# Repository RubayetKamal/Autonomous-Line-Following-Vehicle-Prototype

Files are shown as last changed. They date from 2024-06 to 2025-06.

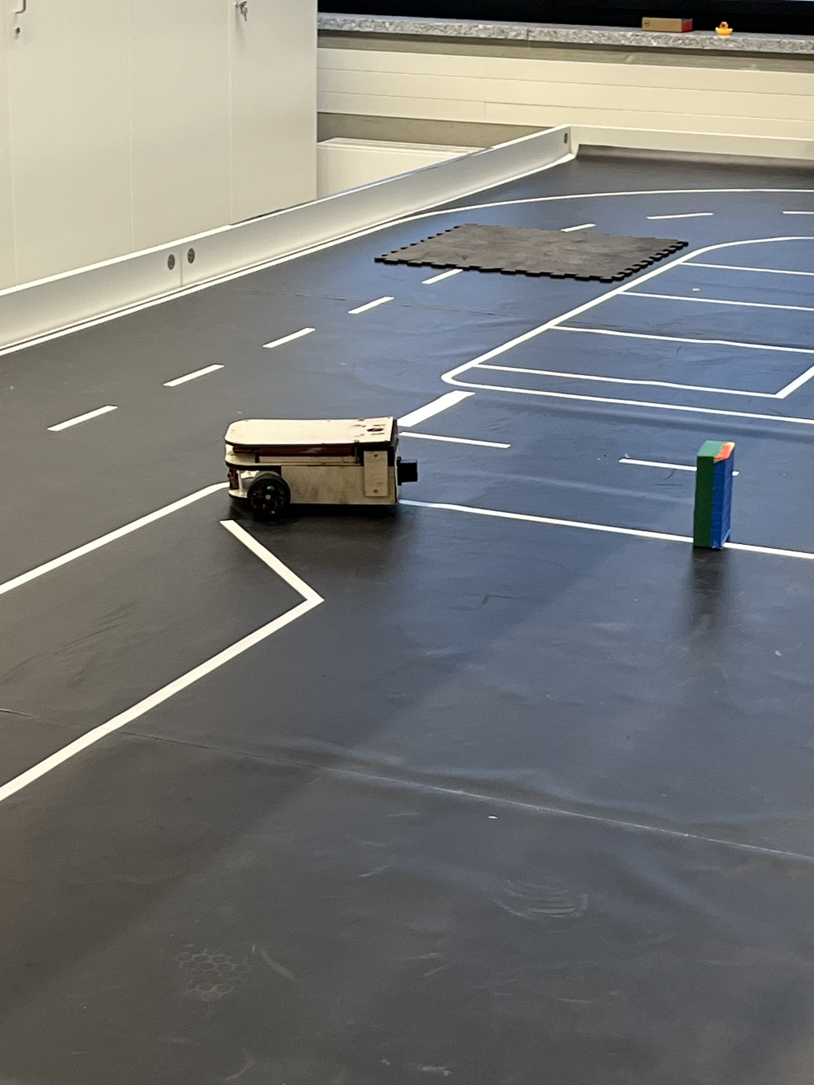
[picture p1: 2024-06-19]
Pictures/IMG_2329.jpg

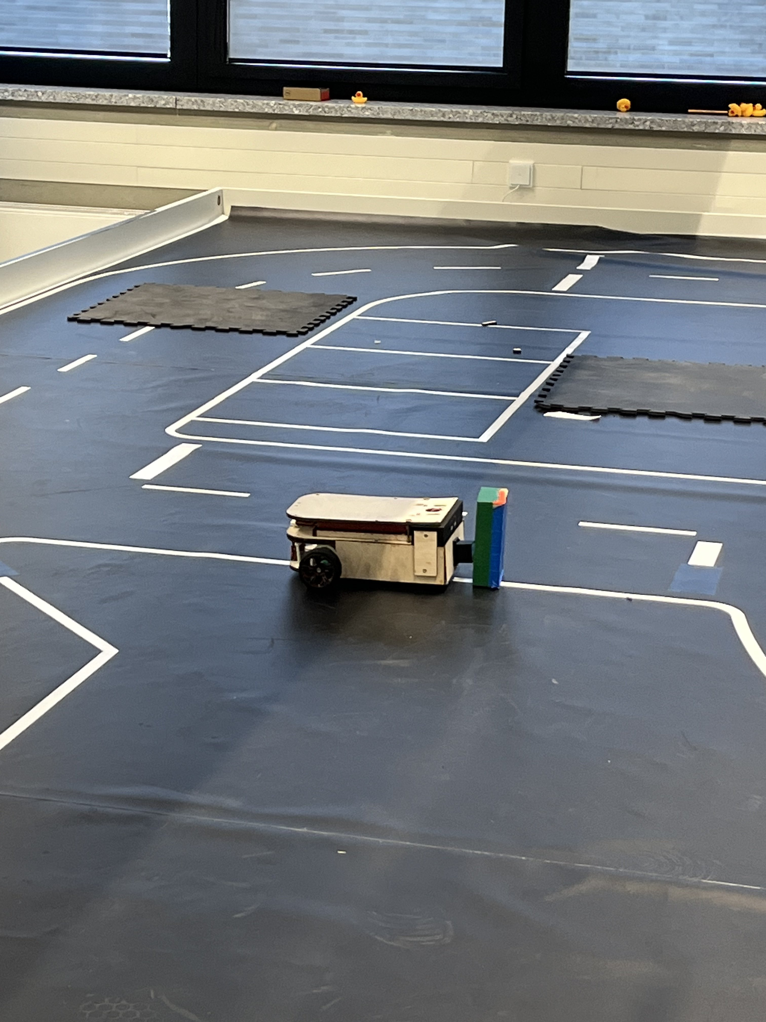
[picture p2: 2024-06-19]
Pictures/IMG_2333.jpg

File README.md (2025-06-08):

# Autonomous Line-Following Vehicle (AVR328P Project)

**Grade: 1,3**

This project involved developing a fully autonomous vehicle prototype using an AVR328P (Arduino Uno), capable of navigating a track independently while responding to environmental cues such as lines, colors, and obstacles.

## Highlights

- 🤝 Collaborated on system design and implementation as part of a team project.
- 🔄 Developed a finite state machine in C using the Arduino library to control vehicle behavior.
- 📍 Integrated a line sensor with an L298N motor driver to enable movement based on line detection.
- 🏎️ Optimized vehicle speed and control to handle a variety of track layouts, including 90° turns, ovals, and figure-eight shapes.
- 📡 Integrated the HC-SR04 ultrasonic sensor for real-time obstacle detection and evaluation.
- 🛠️ Designed and fabricated 2D/3D parts using SolidWorks/Fusion 360, with materials such as PLA and wood, based on collaborative planning.
- 🎨 Calibrated the TCS3200 color sensor to detect specific surroundings and trigger actions like parking or route changes based on detected color.
- 🧩 Modeled the system using SysML after thoroughly analyzing project goals and requirements.

🏆 **Awarded for implementing the most features involving color detection.**

More detailed documentation and attachments are available in this repository.

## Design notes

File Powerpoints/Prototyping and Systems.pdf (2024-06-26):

# PROTOTYPING & SYSTEMS ENGINEERING

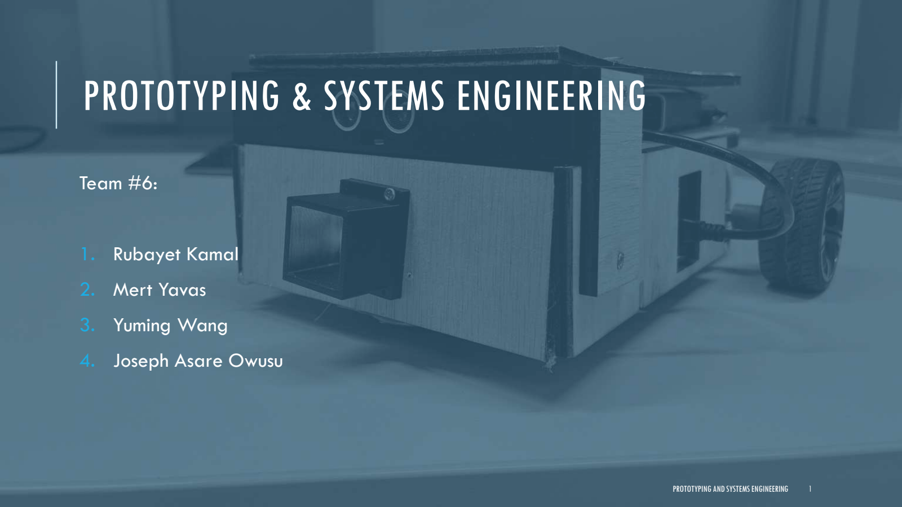
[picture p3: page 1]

# Team #6:

# 1. Rubayet Kamal

# 2. Mert Yavas

# 3. Yuming Wang

# 4. Joseph Asare Owusu

PROTOTYPING AND SYSTEMS ENGINEERING

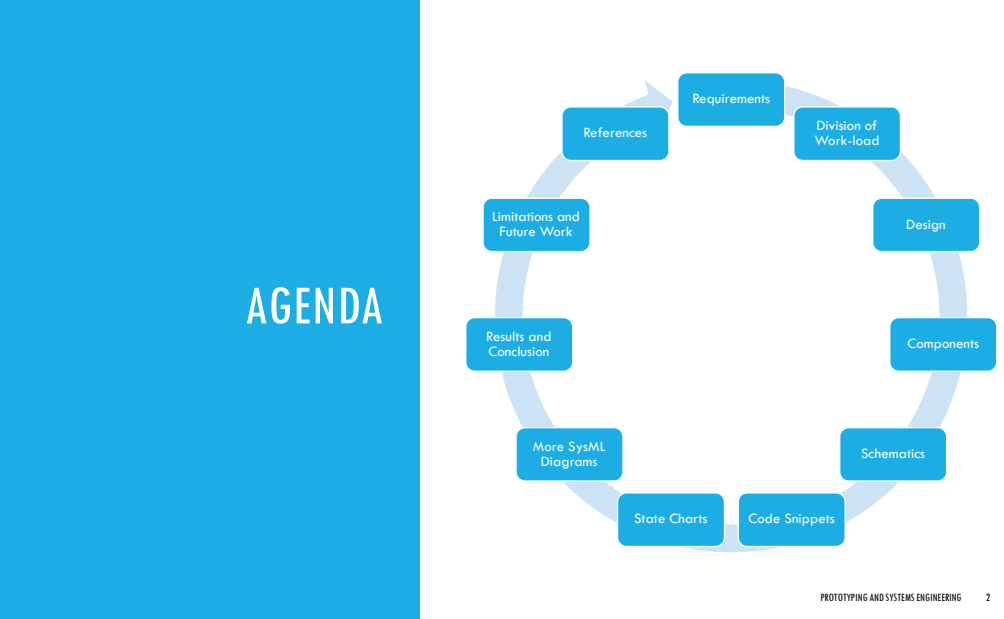
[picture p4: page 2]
AGENDA; PROTOTYPING AND SYSTEMS ENGINEERING; Requirements; Division of Work-load; Design; Components; Schematics; State Charts; Code Snippets; More SysML Diagrams; Results and Conclusion; Limitations and Future Work; References

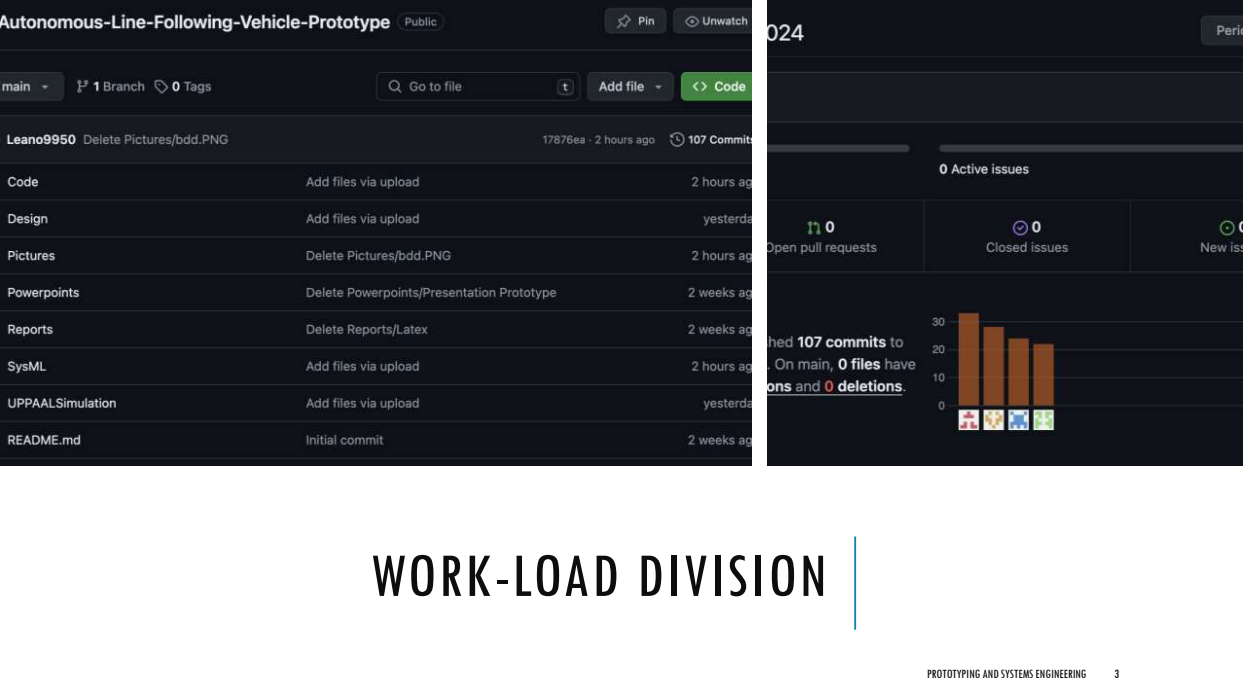
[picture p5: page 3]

WORK-LOAD DIVISION

# Requirements

# Can Follow a Line?

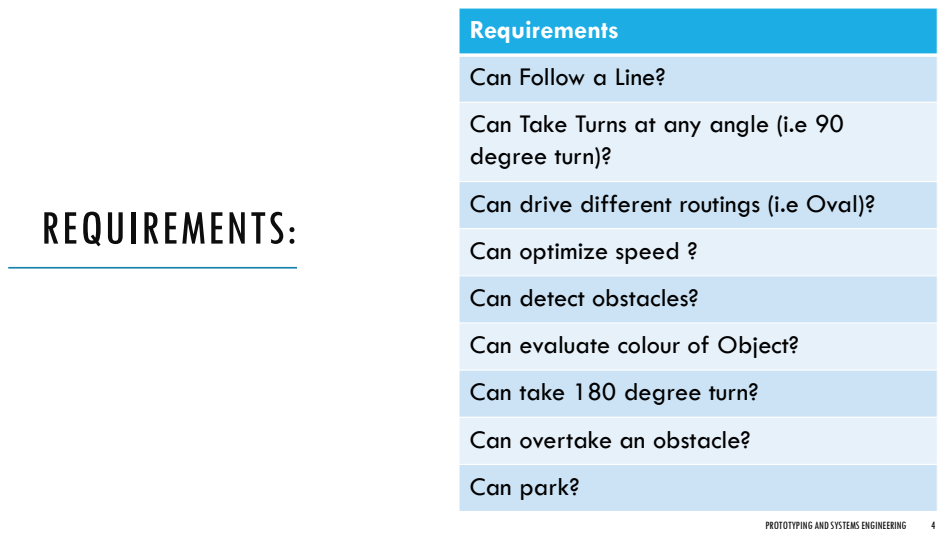
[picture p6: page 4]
REQUIREMENTS:; Can park?

Can Take Turns at any angle (i.e 90
degree turn)?

Can drive different routings (i.e Oval)?

Can optimize speed ?

Can detect obstacles?

Can evaluate colour of Object?

Can take 180 degree turn?

Can overtake an obstacle?

[1]

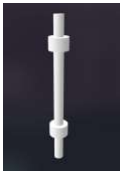
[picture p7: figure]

# PARTS DESIGNED

# VIA SOLIDWORKS AND FUSION 360

## ☐Designed in Solidworks and

Fusion 360.

## ☐.dxf files to laser cut with

wood.

☐.stl to 3D print via PLA.

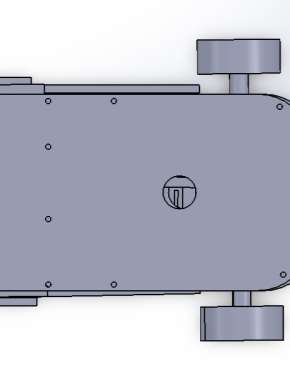
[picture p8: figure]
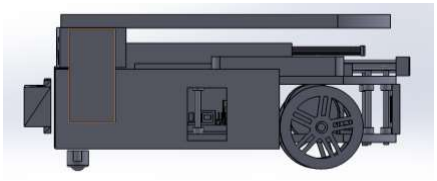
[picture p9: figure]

# FINAL DESIGN

•No components are glued.

•All components are screwed in.

•100 percent modifiable.

[2]

[2]

# SENSORS:

## To Detect Obstacles

## To Detect Change in Line

To Detect Obstacle Color | HC SR-04 Ultrasonic Sensor (Maximum range: 14 cm)
ST 1140 Line Sensor | TCS3200 Color Sensor

[3]

[5]

[4]

# ACTUATORS:

To move the car in any direction.

## - DC Motors (2x)

## - L298N Motor Driver

- Input of 12V from Battery.

## - Output of 5V to Arduino - Used to control speed and

direction of DC Motors.

[6]

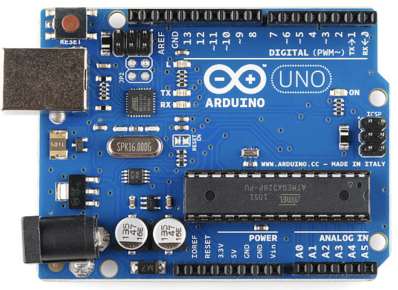
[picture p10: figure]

# MICROCONTROLLER AND POWER SOURCE:

## - 5V Input - 14 Digital Pins - 6 Analog Pins - Used with Arduino IDE

## - Technology LiPo - Cell number 2 - Tension 7.4V - Capacity 3000mAh - Resilience 20C - Weight 210g

- Brain and Energy source of the car.

[8]

[9]

# SCHEMATICAL VIEW FOR HCSR04

Pin Configuration on Ultrasonic Sensor | Pin Configuration on Arduino
Vcc | 5V
TRIG | 4
ECHO | 5
GND | GND

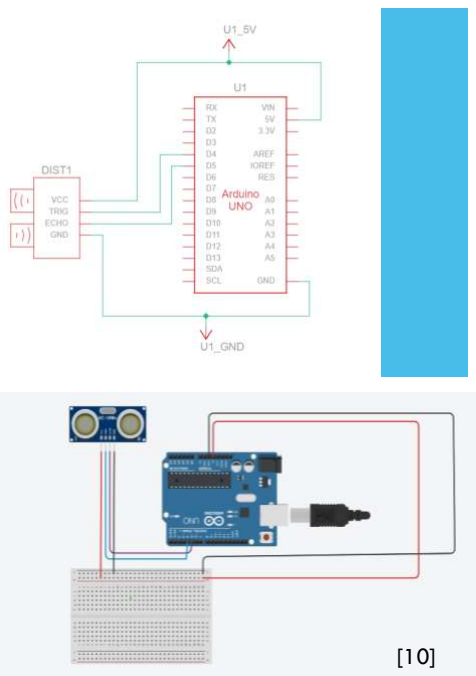
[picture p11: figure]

PROTOTYPING AND SYSTEMS ENGINEERING | 12 [10]

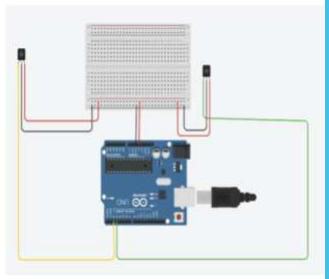
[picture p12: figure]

# SCHEMATICAL VIEW FOR LINE DETECTOR:

Pin on Sensor | Pin Configuration on Arduino
Vcc | 5V
GND | GND
OUTPUT 1 | 2
OUTPUT 2 | 3

[10]

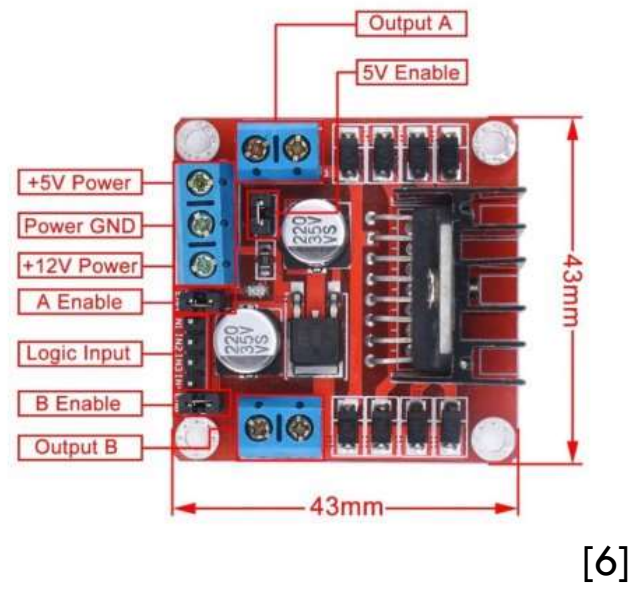
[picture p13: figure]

# SCHEMATICAL VIEW OF

L298N

Pin on Sensor | Pin on Configuration | on Arduino
and | components
IN1 | 10
IN2 | 9
IN3 | 8
IN4 | 7
ENABLE A | 11
ENABLE B | 6
OUTPUT A | MOTOR
OUTPUT B | MOTOR
5V POWER | Vcc
POWER GND | GND
12V POWER | BATTERY

[10]

# SCHEMATICAL VIEW OF TCS3200

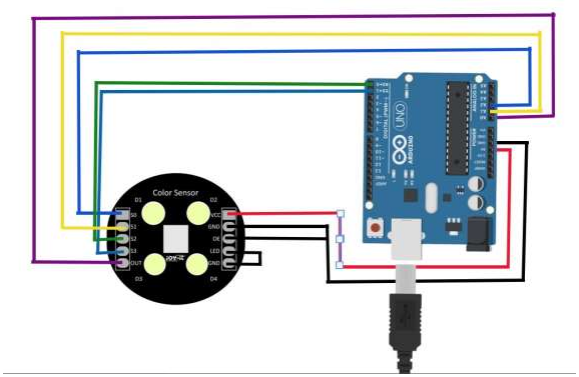
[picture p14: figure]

Pin | on | Sensor | Pin | Configuration on | Arduino
S0 | | | A2
S1 | | | A1
S2 | | | 0
S3 | | | 1
OUT | A0
Vcc | | | 5V
GND | GND
OE | GND
LED | GND
GND | LED

[10]

# COMPLETE SCHEMATIC

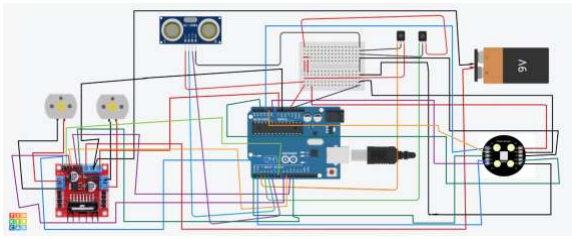
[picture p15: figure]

[10]

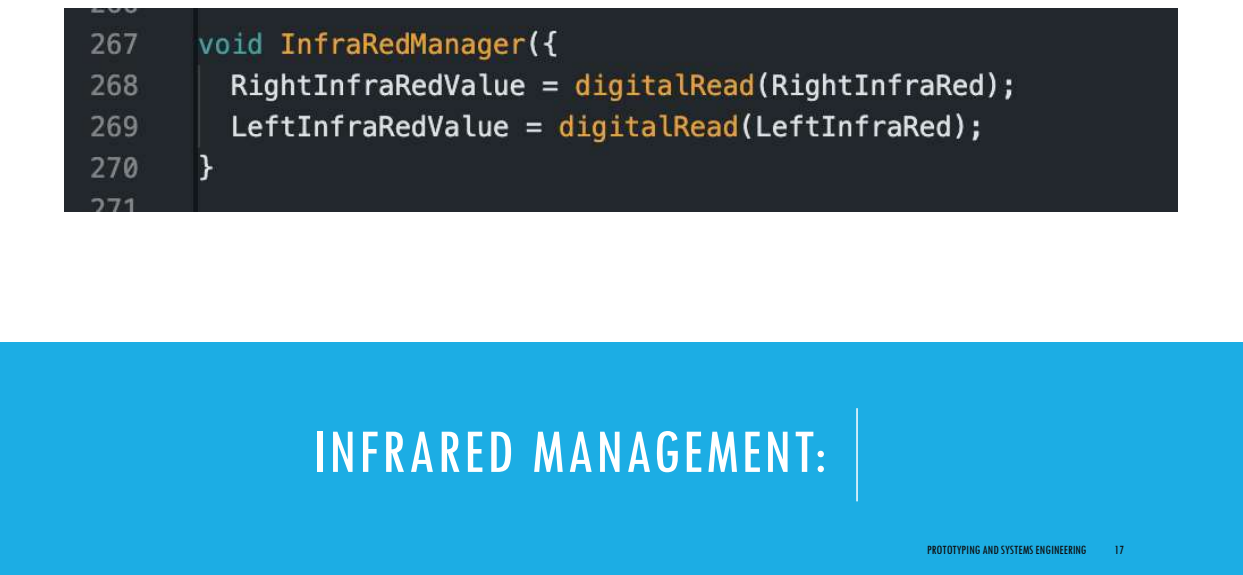
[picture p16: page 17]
INFRARED MANAGEMENT:

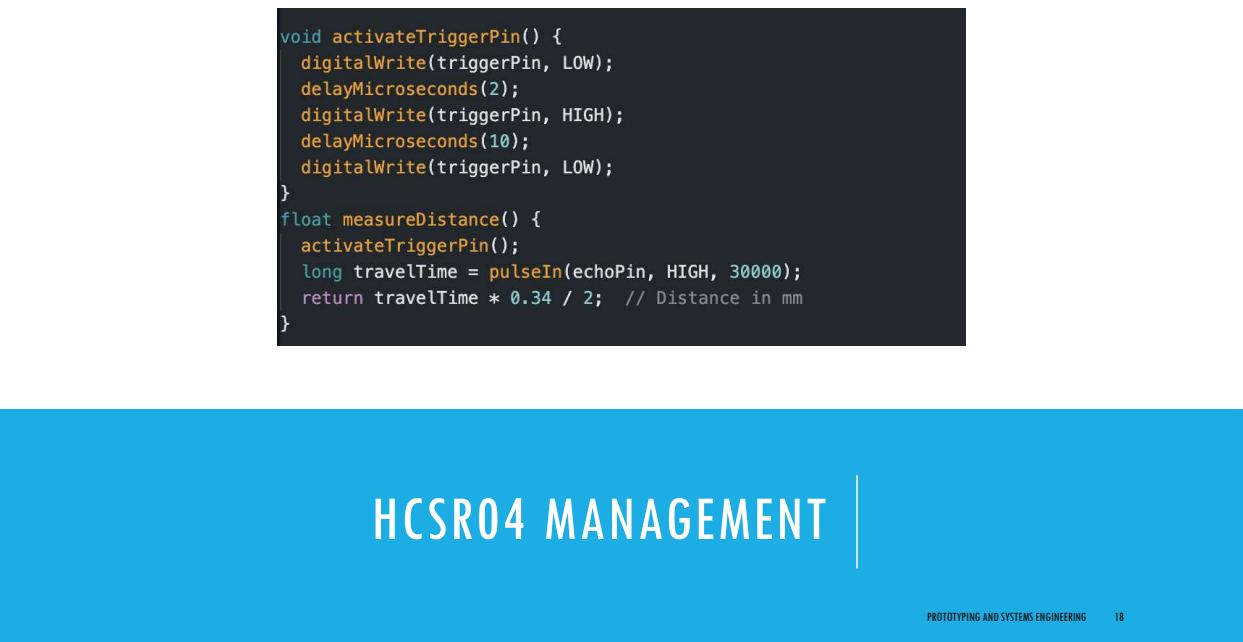
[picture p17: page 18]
HCSR04 MANAGEMENT

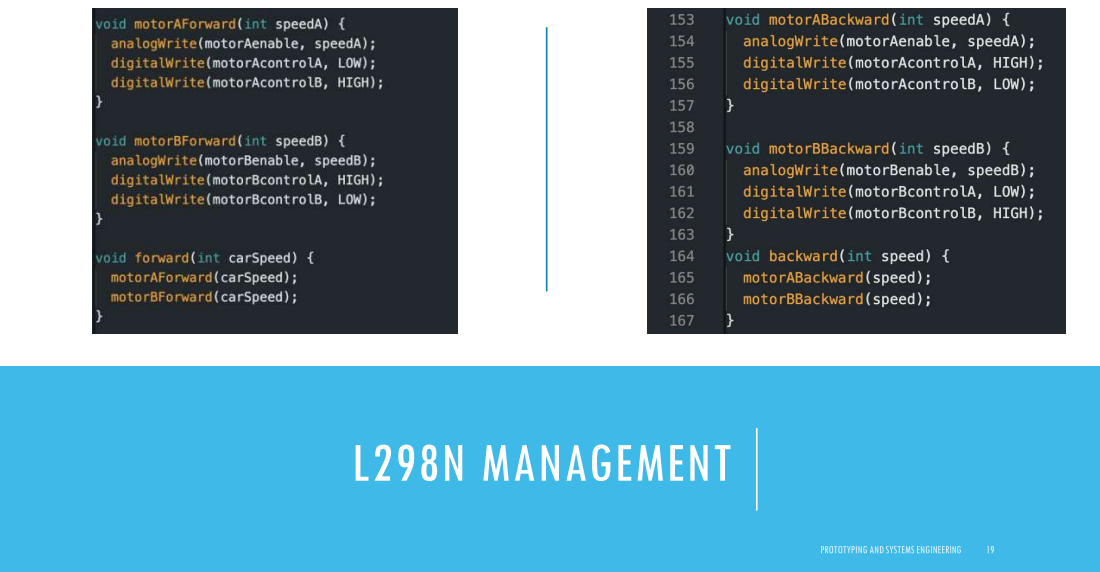
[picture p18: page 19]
L298N MANAGEMENT

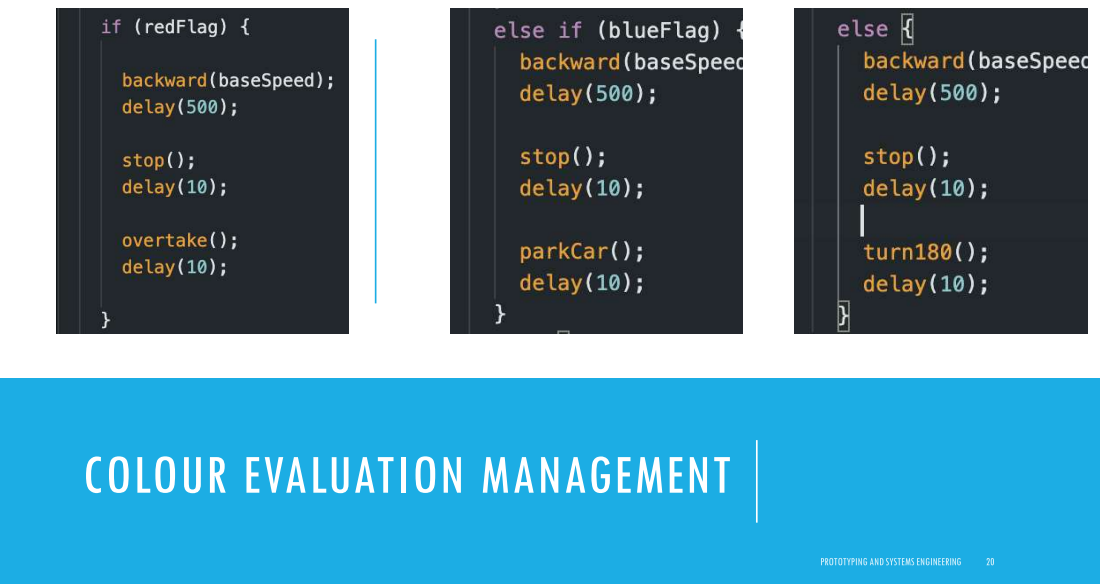
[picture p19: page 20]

COLOUR EVALUATION MANAGEMENT

## State Machine Diagram

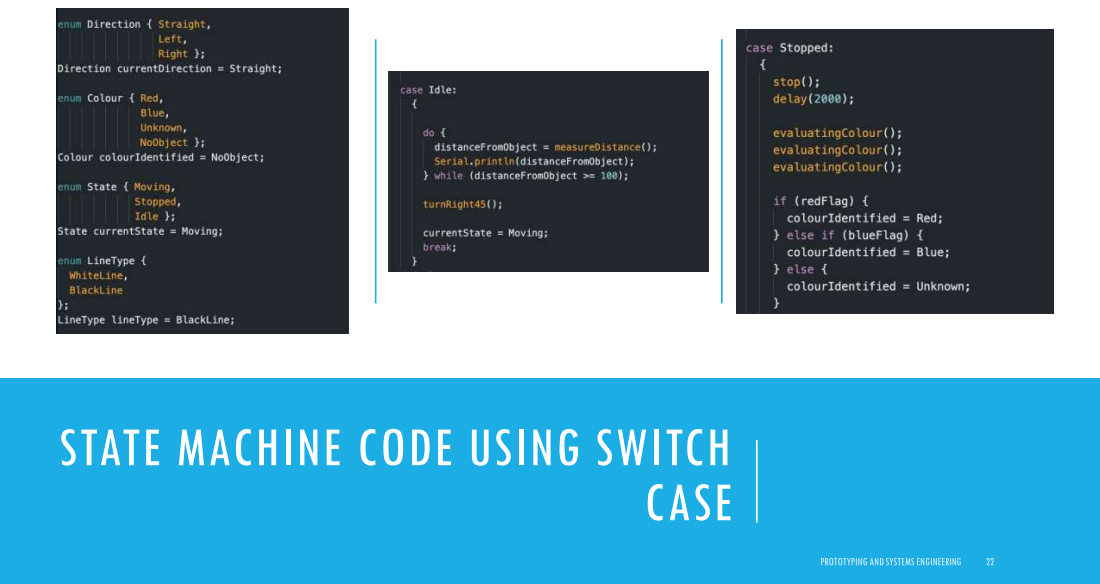
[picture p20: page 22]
CASE

STATE MACHINE CODE USING SWITCH

## Activity Diagram

## Operate Vehicle

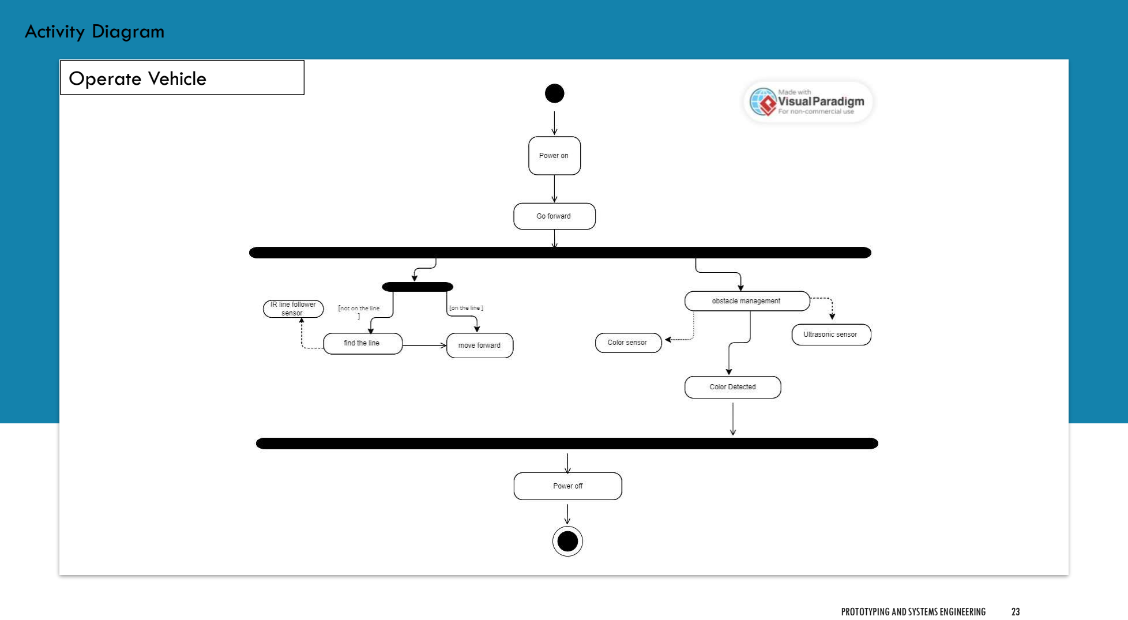
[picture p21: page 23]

## bdd[package][autonomous vehicle prototype]

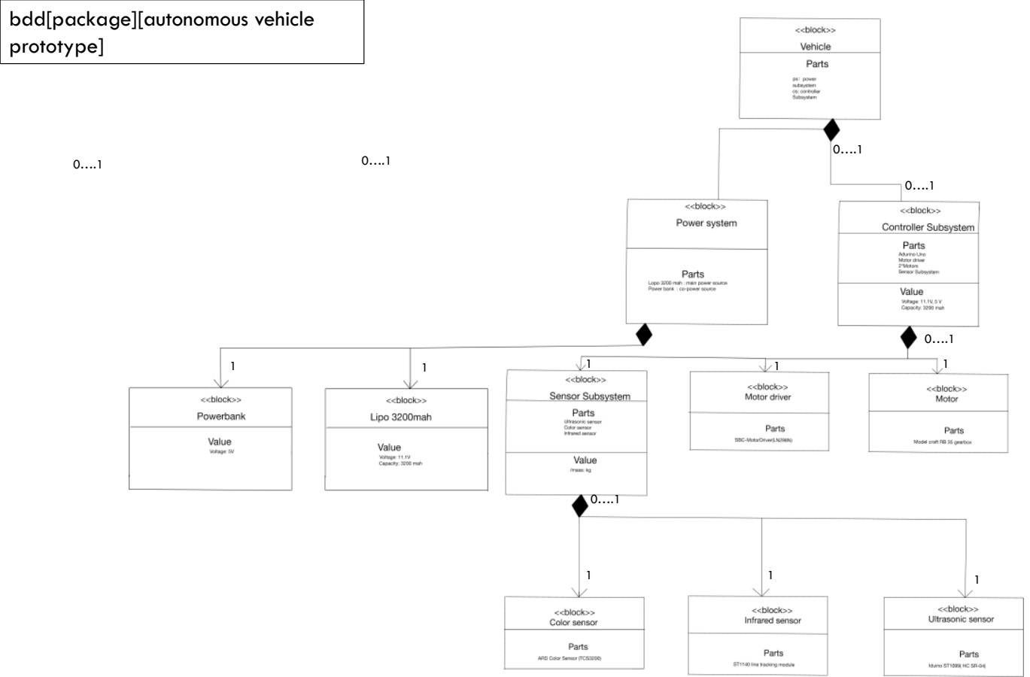
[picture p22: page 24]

1

0….1

0….1

0….1

0….1

1 | 1

0….1 0….1

1 | 1

1

1 | 1

# INTERACTION STRUCTURE

# FOR COLOUR EVALUATION

# INTERACTION STRUCTURE

# FOR FOLLOWING LINE

# INTERACTION STRUCTURE FOR OBSTACLE MANAGEMENT

# RESULTS AND ACCOMPLISHMENT

Requirements | Result
Can Follow a Line? | ✓
Can Take Turns at any angle (i.e 90 degree turn)? | ✓
Can drive different routings (i.e Oval)? | ✓
Can optimize speed ? | ✓
Can detect obstacles? | ✓
Can evaluate colour of Object? | ✓
Can take 180 degree turn? | ✓
Can overtake an obstacle? | ✓
Can park? | ✓

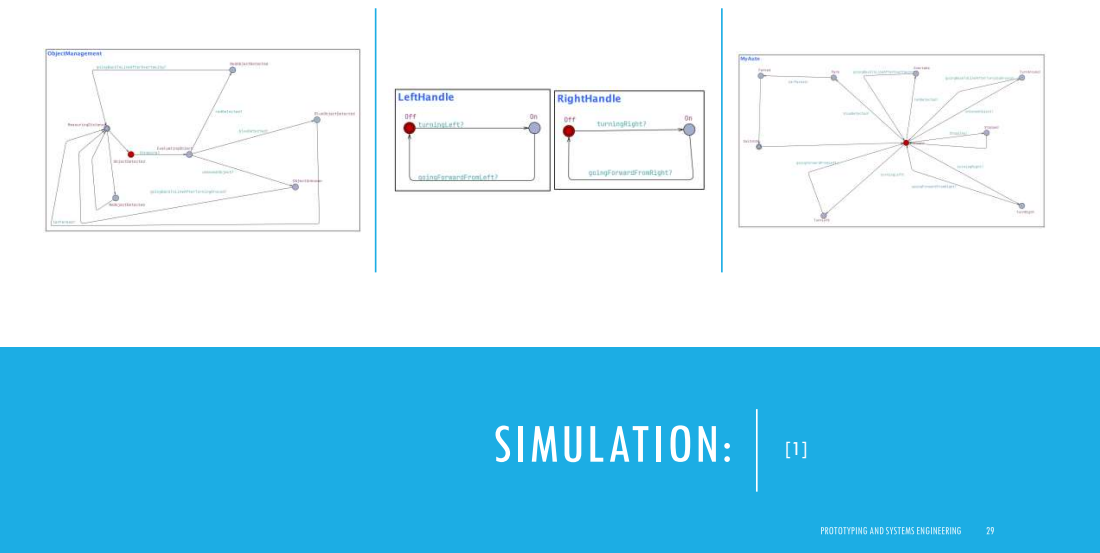
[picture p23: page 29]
SIMULATION:

# CAR FOLLOWING LINE:

# CAR TAKING TURN AT 90 DEGREES:

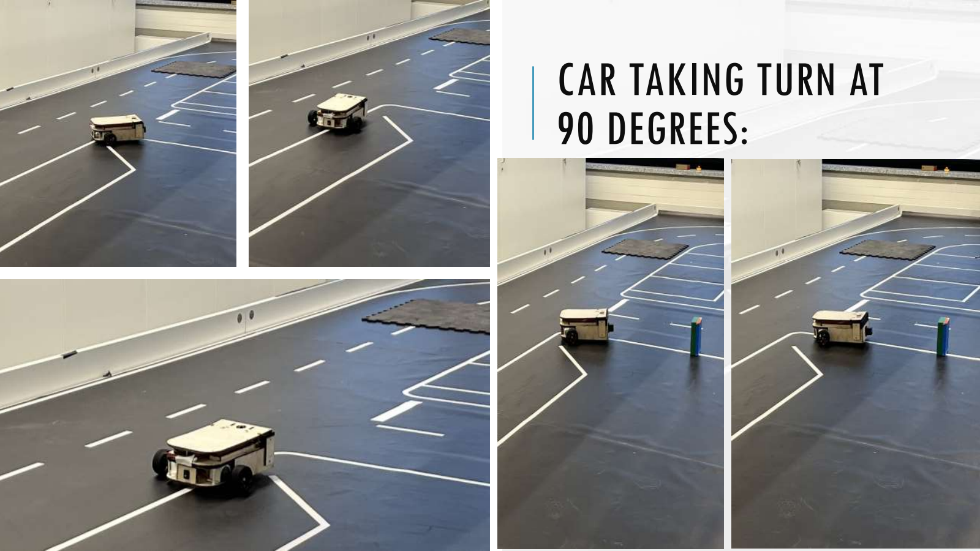
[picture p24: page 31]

# CAR DETECTING OBSTACLE:

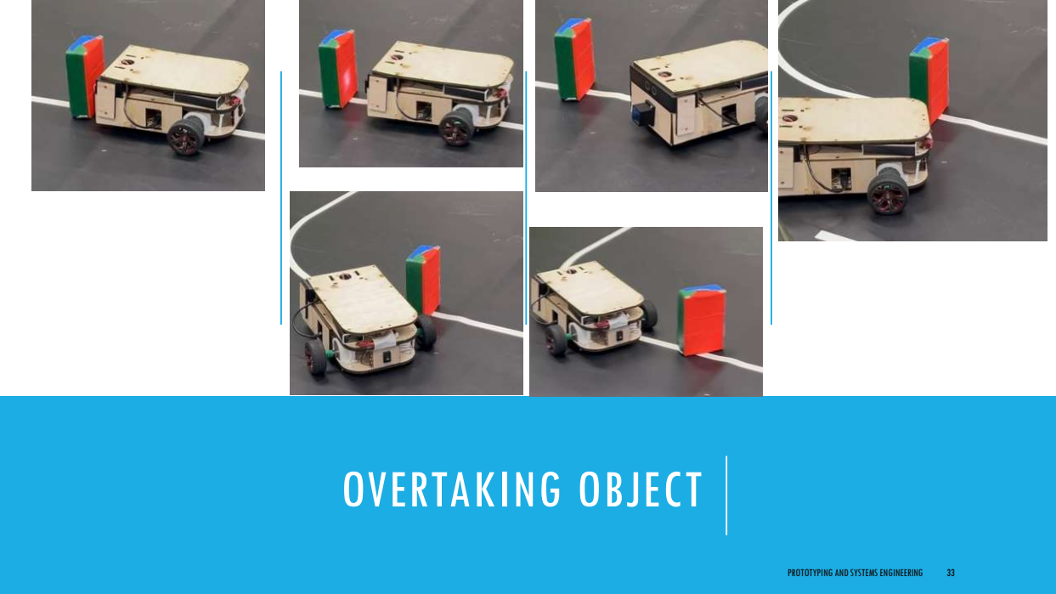
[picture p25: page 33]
OVERTAKING OBJECT

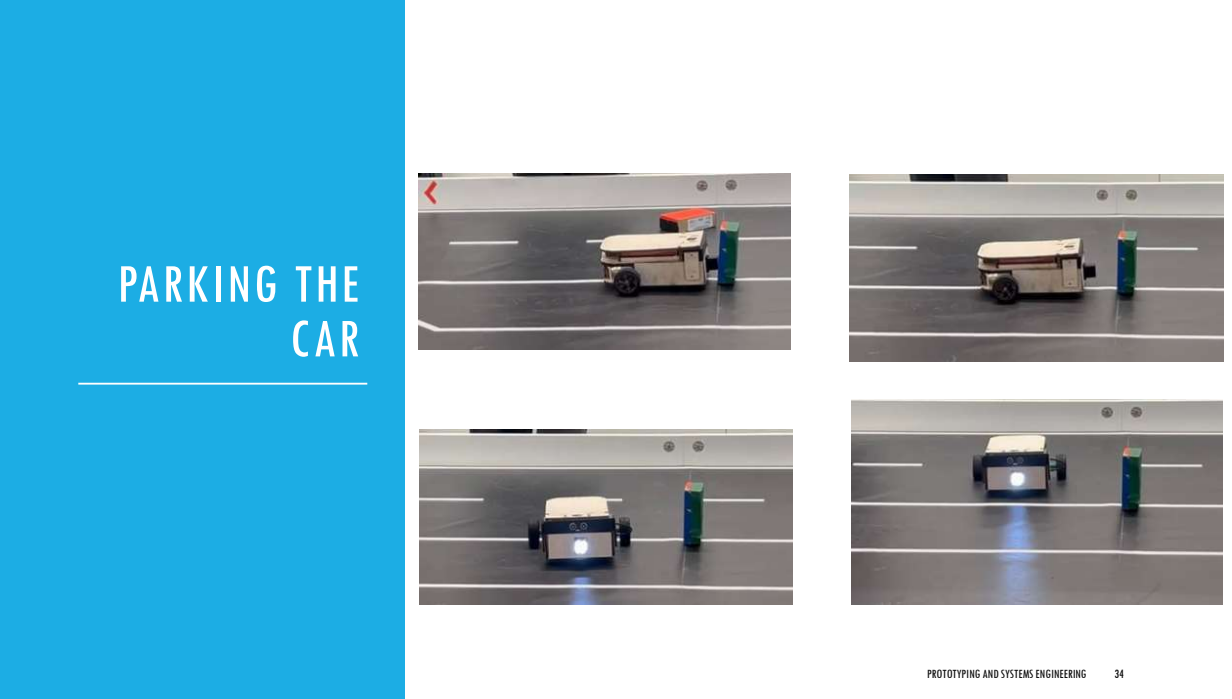
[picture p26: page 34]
PARKING THE CAR

# TURNING 180

# FUTURE WORK:

# 4 wheeled autonomous vehicle

prototype.

# Using Servo front and back to move the ultrasonic so that it can scan

surroundings.

# Will probably need to switch to a different microcontroller as digital

pins in Arduino are limited.

# Maybe use with a Real-Time Operating System for better

response.

[12]

# REFERENCES:

[1] “Uppaal,” UPPAAL, https://uppaal.org/ (accessed Jun. 20, 2024).
[2] “3D CAD Design Software,” SOLIDWORKS, https://www.solidworks.com/ (accessed Jun. 20, 2024).
[3] “Ultrasonic sensor,” Joy, https://joy-it.net/files/files/Produkte/SEN-US01/SEN-US01_Manual_2024-04-15.pdf (accessed Jun. 19, 2024).
[4] “Colorimeter,” https://joy-it.net, https://www.joy-it.net/files/files/Produkte/SEN-Color/SEN-Color_Manual_2021-08-18.pdf (accessed Jun. 19, 2024).
[5] “KY-033 linetracking sensor,” SensorKit, https://sensorkit.joy-it.net/en/sensors/ky-033 (accessed Jun. 20, 2024).
[6] “L298N motor driver module,” Components101, https://components101.com/modules/l293n-motor-driver-module (accessed Jun. 20, 2024).
[7] DC Motor, https://www.handsontec.com/dataspecs/775-Motor.pdf (accessed Jun. 21, 2024).
[8] T. A. Team, “Arduino hardware,” Arduino, https://www.arduino.cc/en/hardware (accessed Jun. 20, 2024).
[9] “Buy Conrad Energy Scale Model Battery Pack (LIPO) 14.8 V 5500 mah no. of cells: 4 20 C Softcase XT90,” Conrad Electronic, https://www.conrad.com/en/p/conrad-energy-scale-model-battery-pack-lipo-14-8-v-5500-mah-no-of-cells-4-20-c-softcase-xt90-1344151.html (accessed Jun. 20, 2024). (https://www.conrad.com/en/p/conrad-energy-scale-model-battery-pack-lipo-14-8-v-5500-mah-no-of-cells-4-20-c-softcase-xt90-1344151.html)
[10] Tinkercad, https://www.tinkercad.com/dashboard (accessed Jun. 20, 2024).
[11] “Online productivity suite,” Visual Paradigm - Online Productivity Suite, https://online.visual-paradigm.com/ (accessed Jun. 20, 2024).
[12] Explore 685+ free racing cars illustrations: Download now - pixabay, https://pixabay.com/illustrations/ai-generated-mouse-racing-car-car-8674235/ (accessed Jun. 20, 2024). (https://pixabay.com/illustrations/ai-generated-mouse-racing-car-car-8674235/)

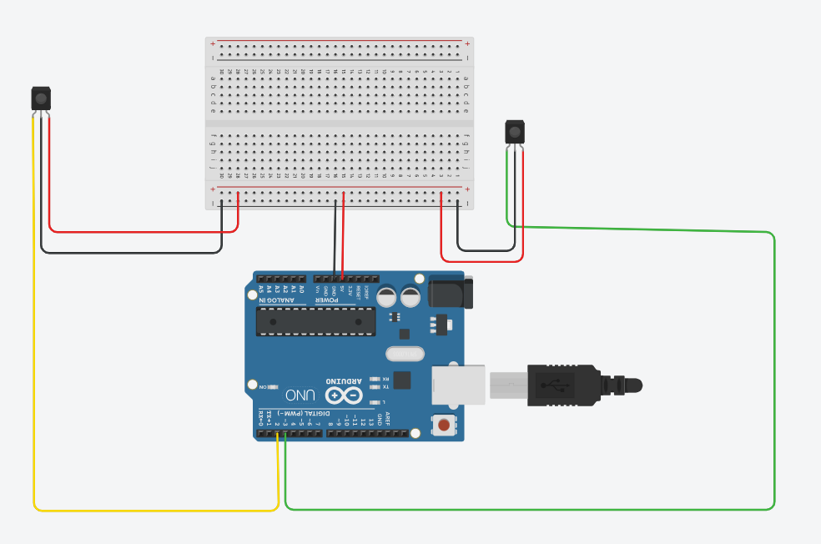
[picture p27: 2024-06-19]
Pictures/ir schematic .png

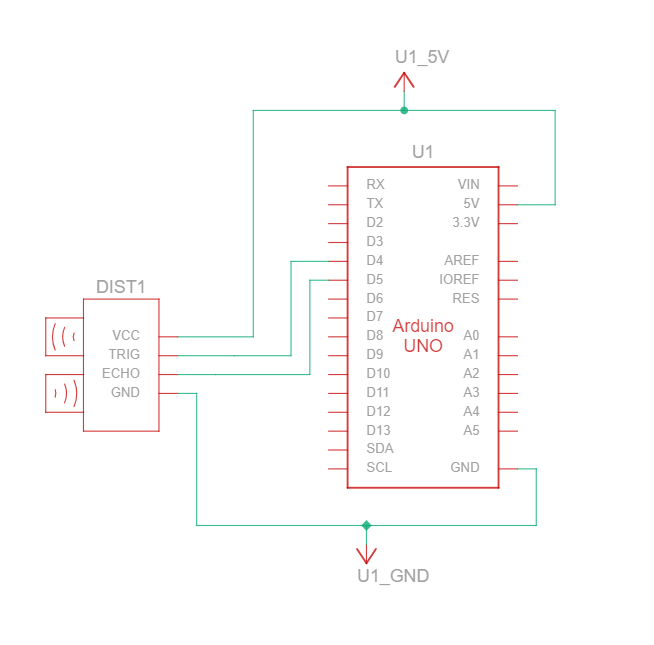
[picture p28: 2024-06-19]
Pictures/ultrasonic schematic.png

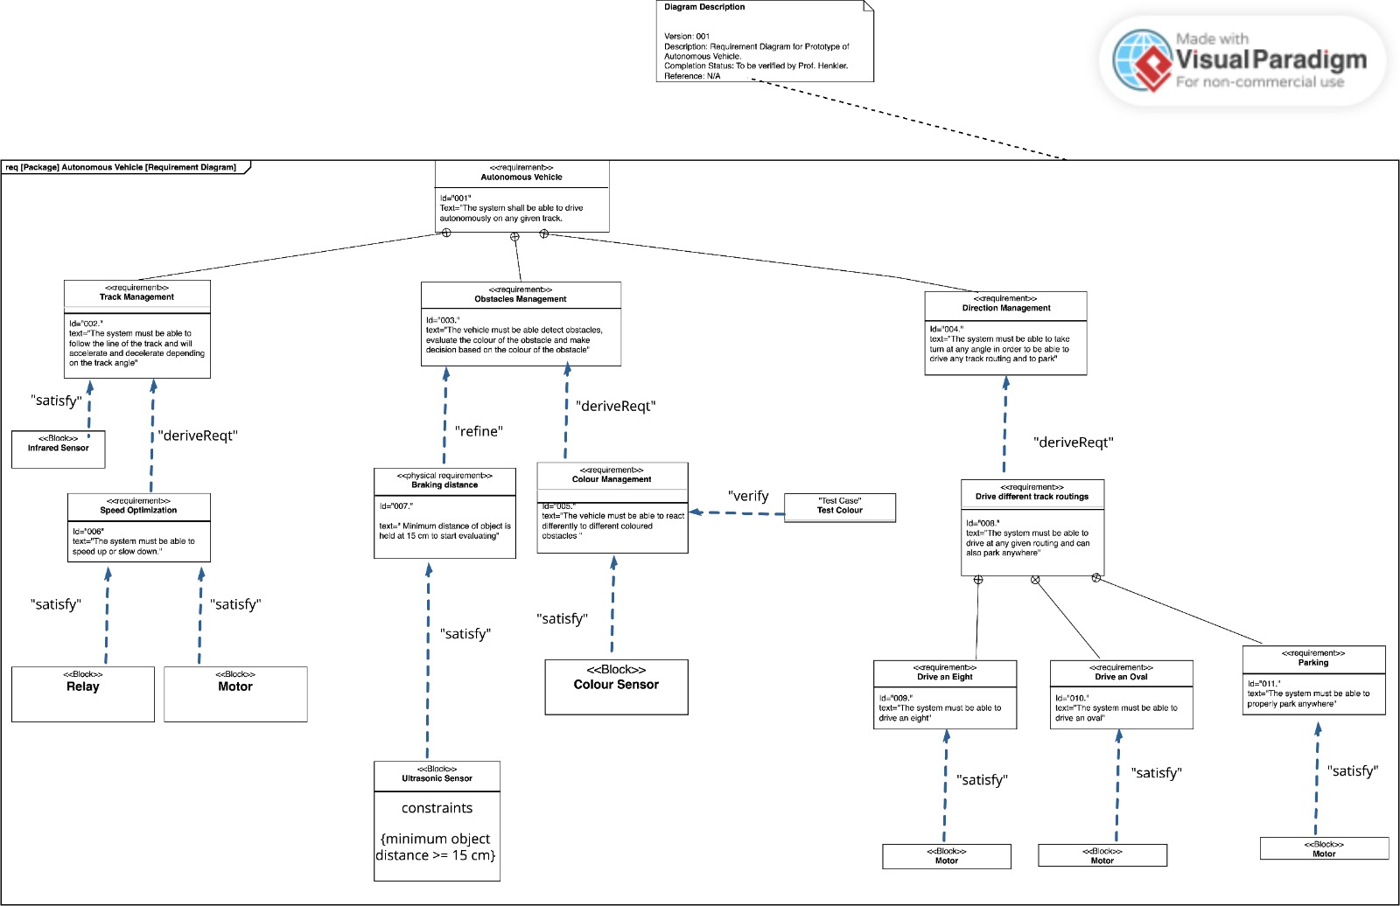
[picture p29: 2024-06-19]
SysML/requirement diagram.jpg

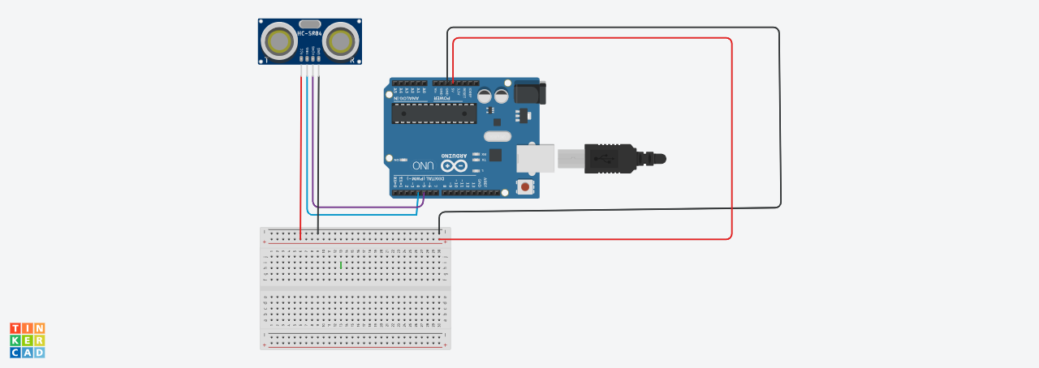
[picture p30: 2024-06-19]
Pictures/Glorious Elzing (1).png

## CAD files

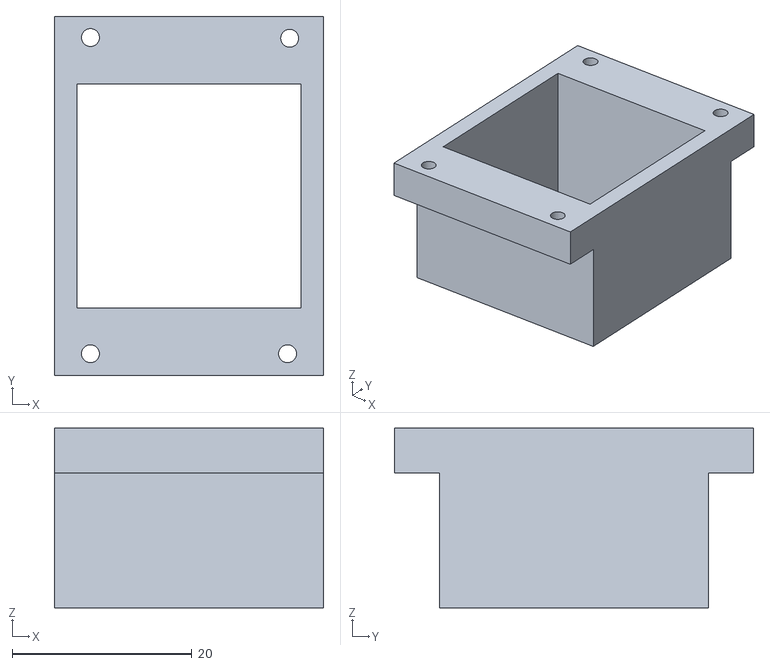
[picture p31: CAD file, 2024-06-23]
Design/ColourSensorCoverAGAIN.stl
30.0 x 40.0 x 20.0

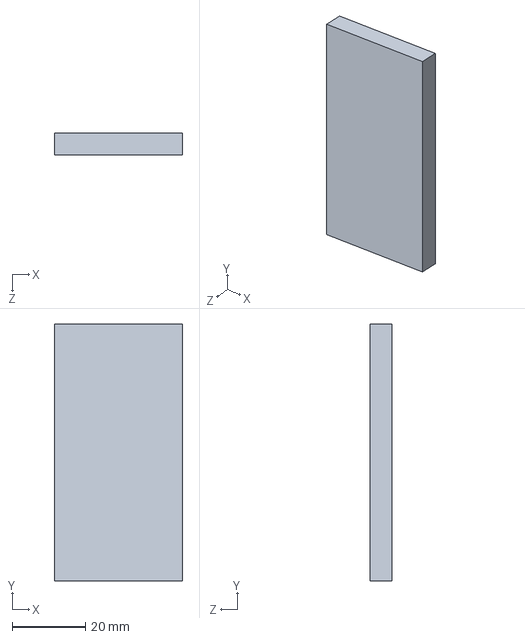
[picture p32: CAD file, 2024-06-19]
Design/ultrasonicSupportHolder.SLDPRT
35.0 x 70.0 x 6.00 mm

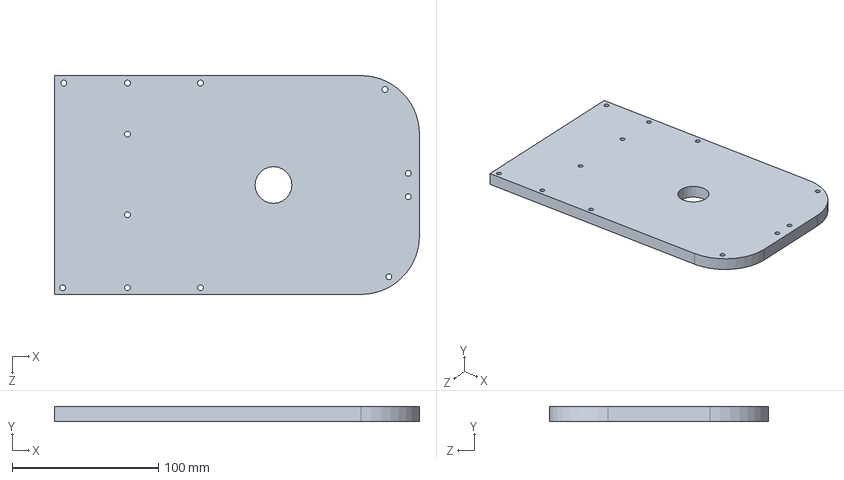
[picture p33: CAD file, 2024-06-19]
Design/Wood10mm.SLDPRT
250.0 x 10.0 x 150.0 mm

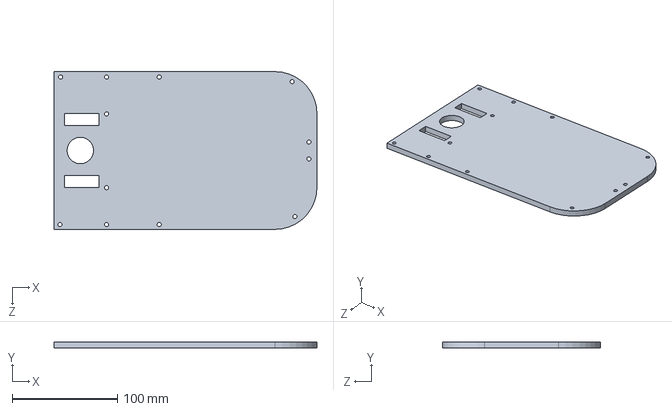
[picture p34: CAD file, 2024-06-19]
Design/Wood6mm.SLDPRT
250.0 x 6.00 x 150.0 mm

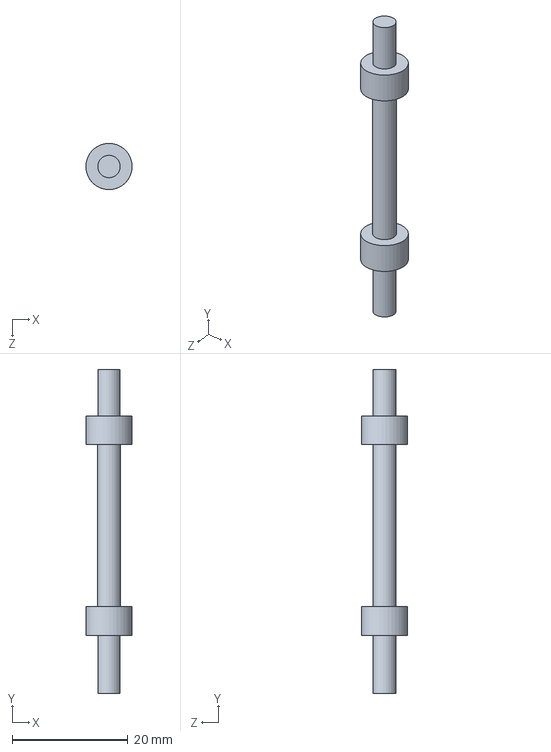
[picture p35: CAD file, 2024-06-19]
Design/supportStick.SLDPRT
7.99 x 56.0 x 8.00 mm

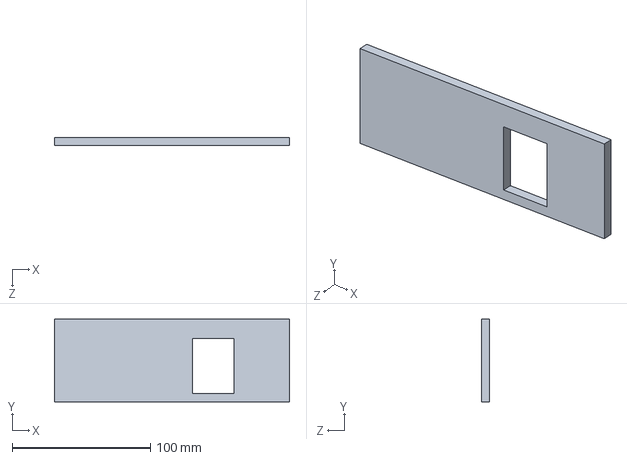
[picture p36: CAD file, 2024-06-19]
Design/sideCoverCable.SLDPRT
170.0 x 60.0 x 6.00 mm

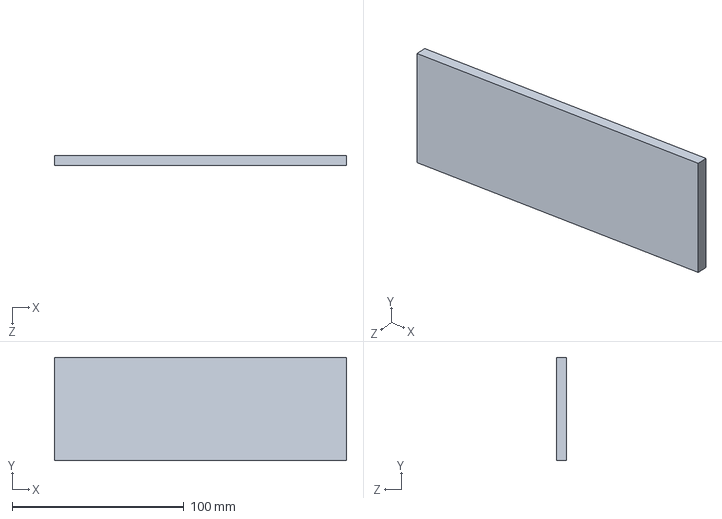
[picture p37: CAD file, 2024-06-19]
Design/sideCover.SLDPRT
170.0 x 60.0 x 6.00 mm

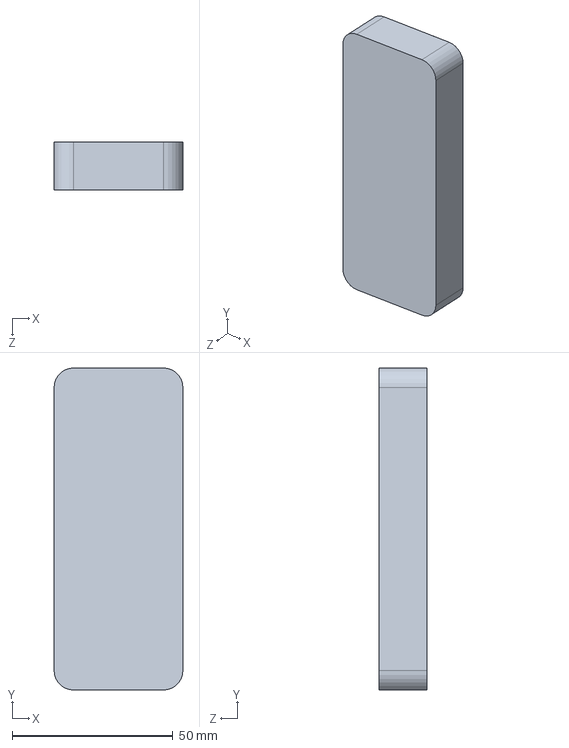
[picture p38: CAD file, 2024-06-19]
Design/powerbank.SLDPRT
40.0 x 100.0 x 15.0 mm

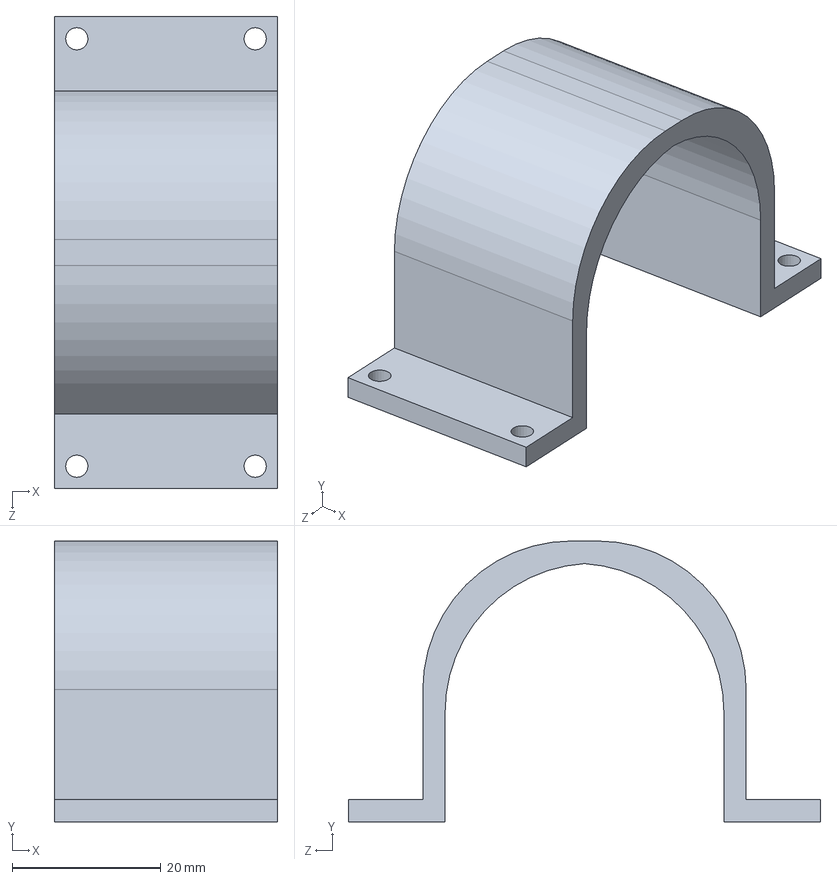
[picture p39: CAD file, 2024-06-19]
Design/motorholder5.SLDPRT
30.0 x 37.8 x 63.5 mm

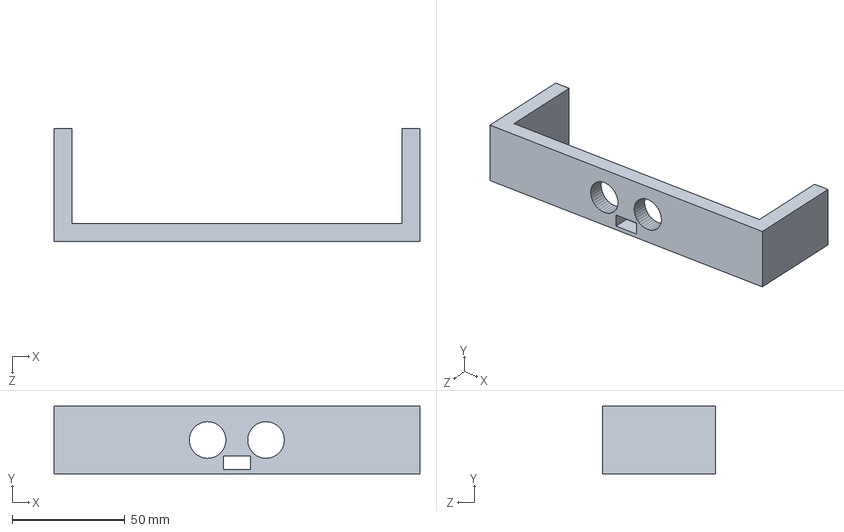
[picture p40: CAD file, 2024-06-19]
Design/Front.SLDPRT
162.0 x 30.0 x 50.0 mm

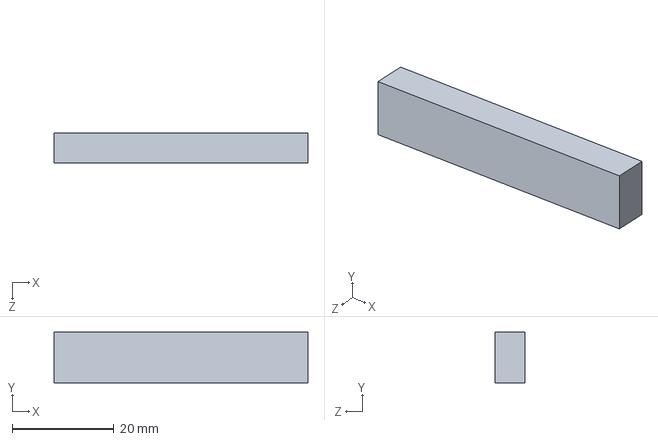
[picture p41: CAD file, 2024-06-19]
Design/batteryHolderShort.SLDPRT
50.0 x 10.0 x 6.00 mm

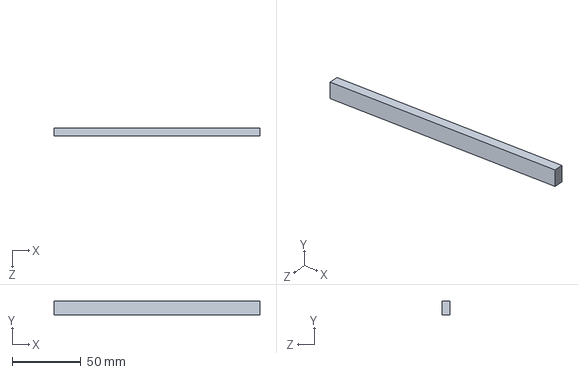
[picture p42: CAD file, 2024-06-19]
Design/batteryHolderLong.SLDPRT
150.0 x 10.0 x 6.00 mm

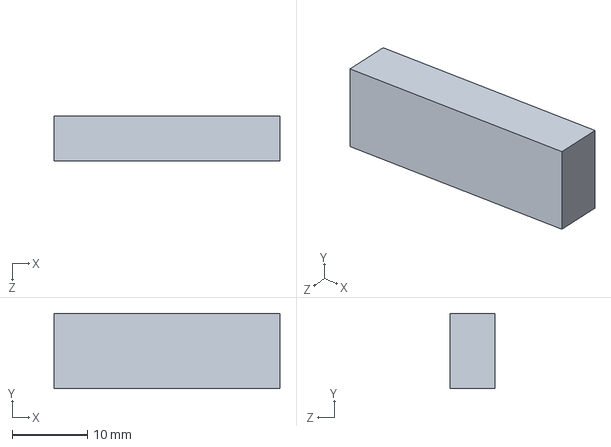
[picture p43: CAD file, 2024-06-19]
Design/batterHolderCable.SLDPRT
30.0 x 10.0 x 6.00 mm

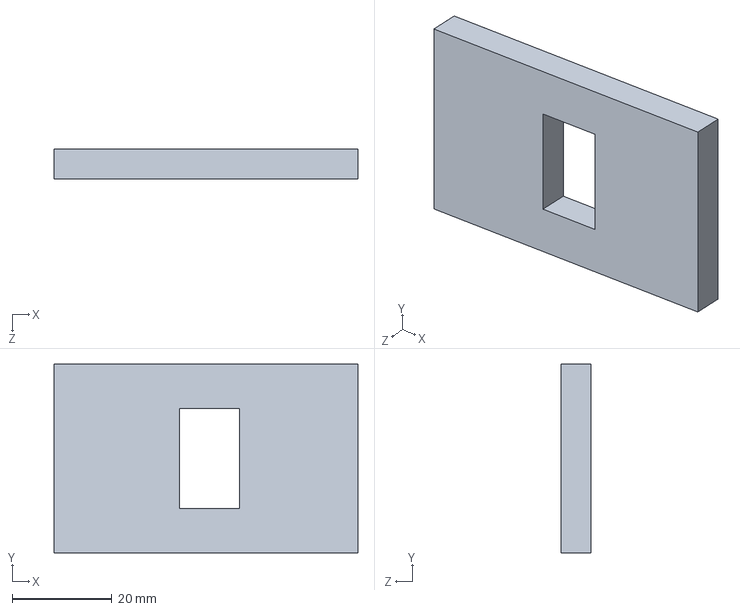
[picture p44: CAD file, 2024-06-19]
Design/backCover.SLDPRT
61.0 x 37.8 x 6.00 mm

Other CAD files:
Design/assembliedCar.SLDASM
Design/ColourSensorCover v2.stl
Design/Front.stl
Design/Wood10mm.DXF
Design/Wood6mm.DXF
Design/assembliedCarSheet.SLDDRW
Design/backCover.DXF
Design/batterHolderCable.DXF
Design/batteryHolderLong.DXF
Design/batteryHolderShort.DXF
Design/motorholder5.STL
Design/sideCover.DXF
Design/sideCoverCable.DXF

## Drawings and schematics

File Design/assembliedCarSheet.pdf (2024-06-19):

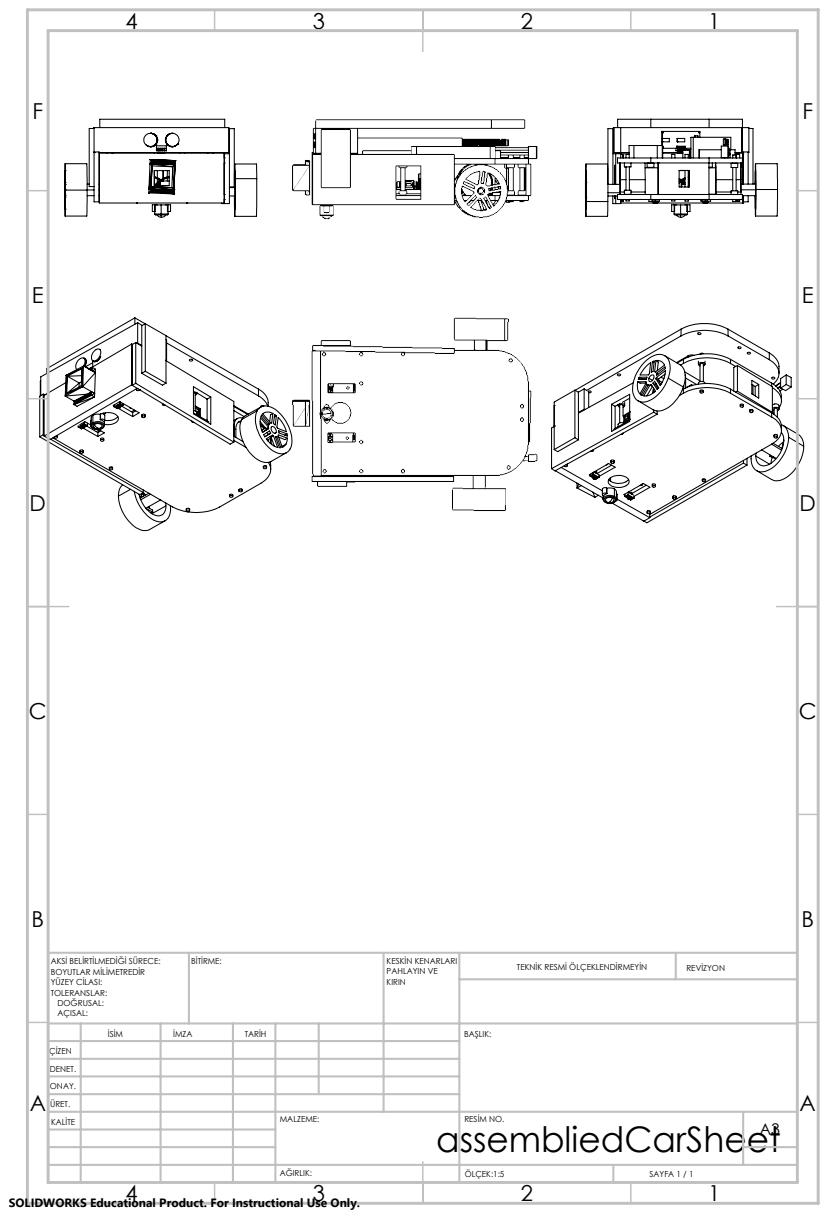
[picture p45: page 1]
BİTİRME:; KESKİN KENARLARI; PAHLAYIN VE; TEKNİK RESMİ ÖLÇEKLENDİRMEYİN; REVİZYON; ÖLÇEK:1:5; SAYFA 1 / 1

AKSİ BELİRTİLMEDİĞİ SÜRECE:
BOYUTLAR MİLİMETREDİR
YÜZEY CİLASI:
TOLERANSLAR:
DOĞRUSAL:
AÇISAL:

İSİM | İMZA | TARİH | | | | BAŞLIK:

ÇİZEN
DENET.
ONAY.
ÜRET.
KALİTE | | | | MALZEME: assembliedCarSheet | RESİM NO. | A3

SOLIDWORKS Educational Product. For Instructional Use Only.

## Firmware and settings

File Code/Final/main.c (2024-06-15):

#include <math.h>
#define noPaverageseInterrupts 1
// Assignment of the sensor pins
#define S0 A2
#define S1 A1
#define S2 0
#define S3 1
#define sensorOut A0


int redMax = 24390.25;
int redMin = 27776.;

int blueMax = 17543.;
int blueMin = 6756.56;


int redColor = 0;
int blueColor = 0;

int redFrequency = 0;
int redEdgeTime = 0;

int blueFrequency = 0;
int blueEdgeTime = 0;

bool redFlag = false;
bool blueFlag = false;

bool whiteLine = true;

const int motorAenable = 11;
const int motorAcontrolA = 10;
const int motorAcontrolB = 9;

const int motorBcontrolA = 8;
const int motorBcontrolB = 7;
const int motorBenable = 6;

const int LeftInfraRed = 2;
const int RightInfraRed = 3;

const int triggerPin = 4;
const int echoPin = 5;
float distanceFromObject = 5000;

int baseSpeed = 100;
int turnSpeed = 70;

int RightInfraRedValue = 1;
int LeftInfraRedValue = 1;

void evaluatingColour() {
  Serial.println("------------------------------");
  {


    digitalWrite(S2, LOW);
    digitalWrite(S3, LOW);

    float(redEdgeTime) = pulseIn(sensorOut, LOW);
    ;
    float(redFrequency) = (1 / (redEdgeTime / 1000000));
    redColor = map(redFrequency, redMax, redMin, 255, 0);
    if (redColor > 255) {
      redColor = 255;
    }
    if (redColor < 0) {
      redColor = 0;
    }

    /*Output of frequency mapped to 0-255*/
    Serial.print("Red Frequency: ");
    Serial.println(redFrequency);
    Serial.print("R = ");
    Serial.println(redColor);
    delay(100);
  }
  {
    digitalWrite(S2, LOW);
    digitalWrite(S3, HIGH);
    /*Frequency measurement of the specified color and its assignment to an RGB value between 0-255*/
    float(blueEdgeTime) = pulseIn(sensorOut, LOW);
    float(blueFrequency) = (1 / (blueEdgeTime / 1000000));
    blueColor = map(blueFrequency, blueMax, blueMin, 255, 0);
    if (blueColor > 255) {
      blueColor = 255;
    }
    if (blueColor < 0) {
      blueColor = 0;
    }
    /*Output of frequency mapped to 0-255*/
    Serial.print("Blue Frequency: ");
    Serial.println(blueFrequency);
    Serial.print("B = ");
    Serial.println(blueColor);
    delay(100);
  }
  Serial.println("------------------------------");
  delay(100);

  if (redColor == 255 && blueColor == 0) {
    Serial.println("No Object Detected");
    delay(200);
  } else if (redColor < 255 && blueColor == 0) {
    Serial.println("Red Detected");
    delay(200);
    blueFlag = false;
    redFlag = true;
  } else if (redColor <= 255 && blueColor > 0) {
    Serial.println("Blue Detected");
    delay(200);
    redFlag = false;
    blueFlag = true;
  }
  Serial.println("------------------------------");
  delay(1000);
}

void activateTriggerPin() {
  digitalWrite(triggerPin, LOW);
  delayMicroseconds(2);
  digitalWrite(triggerPin, HIGH);
  delayMicroseconds(10);
  digitalWrite(triggerPin, LOW);
}

float measureDistance() {
  activateTriggerPin();
  long travelTime = pulseIn(echoPin, HIGH, 30000);
  return travelTime * 0.34 / 2;  // Distance in mm
}

void motorAForward(int speedA) {
  analogWrite(motorAenable, speedA);
  digitalWrite(motorAcontrolA, LOW);
  digitalWrite(motorAcontrolB, HIGH);
}

void motorBForward(int speedB) {
  analogWrite(motorBenable, speedB);
  digitalWrite(motorBcontrolA, HIGH);
  digitalWrite(motorBcontrolB, LOW);
}

void forward(int carSpeed) {
  motorAForward(carSpeed);
  motorBForward(carSpeed);
}

void motorABackward(int speedA) {
  analogWrite(motorAenable, speedA);
  digitalWrite(motorAcontrolA, HIGH);
  digitalWrite(motorAcontrolB, LOW);
}

void motorBBackward(int speedB) {
  analogWrite(motorBenable, speedB);
  digitalWrite(motorBcontrolA, LOW);
  digitalWrite(motorBcontrolB, HIGH);
}
void backward(int speed) {
  motorABackward(speed);
  motorBBackward(speed);
}



void motorAStop() {
  analogWrite(motorAenable, 0);
}

void motorBStop() {
  analogWrite(motorBenable, 0);
}

void stop() {
  motorAStop();
  motorBStop();
}

void turn180() {
  motorABackward(baseSpeed);
  motorBForward(baseSpeed);
  delay(2200);  // Adjust this delay based on your motor speed and desired turn time
  stop();
  delay(10);
}

void turnLeft45() {
  motorABackward(180);
  motorBForward(180);
  delay(200);  // Adjust the delay to achieve a 45-degree turn
  stop();
  delay(1000);
}

void turnLeft90() {
  motorBForward(180);
  motorABackward(180);
  delay(300);  // Adjust the delay to achieve a 90-degree turn
  stop();
  delay(1000);
}

void turnRight45() {
  motorBBackward(180);
  motorAForward(180);
  delay(200);  // Adjust the delay to achieve a 45-degree turn
  stop();
  delay(1000);
}

void turnRight90() {
  motorAForward(180);
  motorBBackward(180);
  delay(400);  // Adjust the delay to achieve a 90-degree turn
  stop();
  delay(1000);
}

void goStraightLong() {
  forward(baseSpeed);
  delay(2500);  // Adjust the delay to move a short distance
  stop();
  delay(1500);
}

void goStraightShort() {
  do {
    forward(baseSpeed);
    RightInfraRedValue = digitalRead(RightInfraRed);
    LeftInfraRedValue = digitalRead(LeftInfraRed);
  } while (RightInfraRedValue == HIGH && LeftInfraRedValue == HIGH);
  stop();
  delay(500);
}

void overtake() {
  turnLeft45();
  distanceFromObject = measureDistance();
  if (distanceFromObject >= 10 && distanceFromObject < 200) {
    stop();
    delay(10);
    backward(baseSpeed);
    delay(600);
    turnRight90();
    goStraightLong();

    motorBForward(180);
    motorABackward(180);
    delay(300);  // Adjust the delay to achieve a 90-degree turn
    stop();
    delay(1000);

    goStraightShort();
  } else {
    goStraightLong();
    turnRight90();
    goStraightShort();
  }
  // turnLeft90();
}


void avoidObject() {
  distanceFromObject = measureDistance();
  Serial.println(distanceFromObject);

  if (distanceFromObject >= 10. && distanceFromObject <= 55.) {
    stop();
    delay(2000);

    evaluatingColour();
    evaluatingColour();
    evaluatingColour();
    Serial.println(redFlag);
    Serial.println(blueFlag);

    if (redFlag) {
      backward(baseSpeed);
      delay(500);
      stop();
      delay(10);
      overtake();
      delay(10);
    } else if (blueFlag) {
      backward(baseSpeed);
      delay(500);
      stop();
      delay(10);
      parkCar();
      delay(10);
    } else {
      backward(baseSpeed);
      delay(500);
      stop();
      delay(10);
      turn180();
      delay(10);
    }
  }
  redFlag = false;
  blueFlag = false;
}
void parkCar() {
  // Turn 90 degrees to the left
  motorAForward(180);
  motorBBackward(180);
  delay(500);  // Adjust the delay to achieve a 90-degree turn
  stop();
  delay(1000);


  stop();
  delay(10);  // Small delay after stopping

  // Go back a little bit
  motorABackward(200);
  motorBBackward(220);
  delay(500);  // Adjust the delay to move back a little bit
  do {
    stop();
  } while (LeftInfraRedValue == HIGH && RightInfraRedValue == HIGH);
}



void setup() {
  pinMode(motorAcontrolA, OUTPUT);
  pinMode(motorAcontrolB, OUTPUT);
  pinMode(motorBcontrolA, OUTPUT);
  pinMode(motorBcontrolB, OUTPUT);
  pinMode(motorAenable, OUTPUT);
  pinMode(motorBenable, OUTPUT);

  pinMode(LeftInfraRed, INPUT);
  pinMode(RightInfraRed, INPUT);

  pinMode(triggerPin, OUTPUT);
  pinMode(echoPin, INPUT);

  analogWrite(motorAenable, 255);  //inital speed of Motors
  analogWrite(motorBenable, 255);

  pinMode(S0, OUTPUT);
  pinMode(S1, OUTPUT);
  pinMode(S2, OUTPUT);
  pinMode(S3, OUTPUT);
  pinMode(sensorOut, INPUT);
  /*Scaling the output frequency
 S0/S1
 LOW/LOW=AUS, LOW/HIGH=2%,
 HIGH/LOW=20%, HIGH/HIGH=100%*/
  digitalWrite(S0, HIGH);
  digitalWrite(S1, LOW);
  Serial.begin(9600);

}

void InfraRedManager() {
  RightInfraRedValue = digitalRead(RightInfraRed);
  LeftInfraRedValue = digitalRead(LeftInfraRed);
}

void loop() {
  InfraRedManager();
  avoidObject();
  if (whiteLine) {
    if (LeftInfraRedValue == HIGH && RightInfraRedValue == HIGH) {
      forward(baseSpeed);                                                 // Black line detected, go straight
    } else if (LeftInfraRedValue == LOW && RightInfraRedValue == HIGH) {  // Left sensor off the line, right sensor on the line, turn left
      motorABackward(150);                                                //reduce speed of left motor
      motorBForward(baseSpeed + turnSpeed);                               //increase speed of right motor
    } else if (LeftInfraRedValue == HIGH && RightInfraRedValue == LOW) {  //// Right sensor off the line, left sensor on the line, turn right
      motorAForward(baseSpeed + turnSpeed);                               //increase speed of left motor
      motorBBackward(150);                                                //reduce speed of right motor
    } else {                                                              //error meaning both sensors are not finding a black line, meaning car is off tracks
      backward(baseSpeed);                                                //reduce speed of right motor
    }



    //////For Black Line:



  } else {
    if (LeftInfraRedValue == LOW && RightInfraRedValue == LOW) {
      forward(baseSpeed);                                                 // Black line detected, go straight
    } else if (LeftInfraRedValue == HIGH && RightInfraRedValue == LOW) {  // Left sensor off the line, right sensor on the line, turn left
      motorABackward(150);                                                //reduce speed of left motor
      motorBForward(baseSpeed + turnSpeed);                               //increase speed of right motor
    } else if (LeftInfraRedValue == LOW && RightInfraRedValue == HIGH) {  //// Right sensor off the line, left sensor on the line, turn right
      motorAForward(baseSpeed + turnSpeed);                               //increase speed of left motor
      motorBBackward(150);                                                //reduce speed of right motor
    } else {                                                              //error meaning both sensors are not finding a black line, meaning car is off tracks
      backward(baseSpeed);                                                //reduce speed of right motor
    }
  }
}

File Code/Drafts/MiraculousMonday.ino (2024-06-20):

#include <math.h>
const int motorAenable = 11;
const int motorAcontrolA = 10;
const int motorAcontrolB = 9;

const int motorBcontrolA = 8;
const int motorBcontrolB = 7;
const int motorBenable = 6;

const int LeftInfraRed = 2;
const int RightInfraRed = 3;

const int triggerPin = 4;
const int echoPin = 5;
float distanceFromObject = 5000;

int baseSpeed = 100;
int turnSpeed = 70;

const int colourDetectingPinOne = 0;  //colourDetectingPinOne
const int colourDetectingPinTwo = 1;  //colourDetectingPinTwo

const int frequencyDetectingPinOne = A2;  //S0
const int frequencyDetectingPinTwo = A1;  //S1

const int colourSensorOutput = A0;  //colourSensorOutput
const int colourSensorLED = A3;

bool redFlag = false;
bool blueFlag = false;

int redMin = 0;
int redMax = 1;

int blueMin = 0;
int blueMax = 1;

int redColor = 0;
int blueColor = 0;

float redFrequency = 0.;
float redEdgeTime = 0.;

float blueFrequency = 0.;
float blueEdgeTime = 0.;

void checkingRed() {
  digitalWrite(colourDetectingPinOne, LOW);  //Red Filter Set
  digitalWrite(colourDetectingPinTwo, LOW);
  redEdgeTime = pulseIn(colourSensorOutput, HIGH) + pulseIn(colourSensorOutput, LOW);  //Period of Red
  redFrequency = (1 / (redEdgeTime / 1000000));                                        //frequency of Red
  redColor = map(redFrequency, redMax, redMin, 255, 0);                                //mapped frequency
  redColor = constrain(redColor, 0, 255);                                              //ensures it does not go outside 0 and 255
  Serial.print("Red Frequency: ");
  Serial.println(redFrequency);
  Serial.print("R = ");
  Serial.println(redColor);
  delay(100);
}

void checkingBlue() {
  digitalWrite(colourDetectingPinOne, LOW);
  digitalWrite(colourDetectingPinTwo, HIGH);
  /*Frequency measurement of the specified color and its assignment to an RGB value between 0-255*/
  blueEdgeTime = pulseIn(colourSensorOutput, HIGH) + pulseIn(colourSensorOutput, LOW);
  blueFrequency = (1 / (blueEdgeTime / 1000000));
  blueColor = map(blueFrequency, blueMax, blueMin, 255, 0);
  blueColor = constrain(blueColor, 0, 255);

  Serial.print("Blue Frequency: ");
  Serial.println(blueFrequency);
  Serial.print("B = ");
  Serial.println(blueColor);
  delay(100);
}

void determiningColour() {

  //
}

void evaluatingColour() {
  Serial.println("------------------------------");
  checkingRed();
  checkingBlue();
  Serial.println("------------------------------");
  delay(100);
  determiningColour();
}

void activateTriggerPin() {
  digitalWrite(triggerPin, LOW);
  delayMicroseconds(2);
  digitalWrite(triggerPin, HIGH);
  delayMicroseconds(10);
  digitalWrite(triggerPin, LOW);
}
float measureDistance() {
  activateTriggerPin();
  long travelTime = pulseIn(echoPin, HIGH, 30000);
  return travelTime * 0.34 / 2;  // Distance in mm
}

void motorAForward(int speedA) {
  analogWrite(motorAenable, speedA);
  digitalWrite(motorAcontrolA, LOW);
  digitalWrite(motorAcontrolB, HIGH);
}

void motorBForward(int speedB) {
  analogWrite(motorBenable, speedB);
  digitalWrite(motorBcontrolA, HIGH);
  digitalWrite(motorBcontrolB, LOW);
}

void motorABackward(int speedA) {
  analogWrite(motorAenable, speedA);
  digitalWrite(motorAcontrolA, HIGH);
  digitalWrite(motorAcontrolB, LOW);
}

void motorBBackward(int speedB) {
  analogWrite(motorBenable, speedB);
  digitalWrite(motorBcontrolA, LOW);
  digitalWrite(motorBcontrolB, HIGH);
}
void backward() {
  motorABackward(baseSpeed);
  motorBBackward(baseSpeed);
}



void motorAStop() {
  analogWrite(motorAenable, 0);
}

void motorBStop() {
  analogWrite(motorBenable, 0);
}

void forward(int carSpeed) {
  motorAForward(carSpeed);
  motorBForward(carSpeed);
}

void stop() {
  motorAStop();
  motorBStop();
}

void turn180() {
  motorABackward(baseSpeed);
  motorBForward(baseSpeed);
  delay(1000);
  stop();
}
void turnLeft(int leftWheelBackSpeed) {
  motorABackward(leftWheelBackSpeed);    //reduce speed of left motor
  motorBForward(baseSpeed + turnSpeed);  //increase speed of right motor
}

void turnRight(int rightWheelBackSpeed) {
  motorAForward(baseSpeed + turnSpeed);  //increase speed of left motor
  motorBBackward(rightWheelBackSpeed);   //reduce speed of right motor
}

void goAround() {
  stop();
  delay(500);

  turnRight(baseSpeed);
  delay(500);  //to adjust for desired turn angle
  stop();
  delay(500);

  forward(baseSpeed);
  delay(1000);  //adjust
  stop();
  delay(500);

  turnLeft(baseSpeed);
  delay(500);  //adjust
  stop();
  delay(500);

  forward(baseSpeed);
  delay(1000);  //adjust
  stop();
  delay(500);

  // Turn left to re-align with the original path
  turnLeft(baseSpeed);
  delay(500);  // Adjust this delay based on your motor speed and desired turn angle
  stop();
  delay(500);

  // Move forward to continue on the original path
  forward(baseSpeed);
  delay(1000);  // Adjust this delay based on the size of the object
  stop();
  delay(500);

  // Turn right to re-align with the original path
  turnRight(baseSpeed);
  delay(500);  // Adjust this delay based on your motor speed and desired turn angle
  stop();
  delay(500);
}

void avoidObject() {
  distanceFromObject = measureDistance();
  if (distanceFromObject <= 400.) {
    stop();
    delay(10);
    
    evaluatingColour();
    if (redFlag) {
      turn180();
      delay(10);
      redFlag = false;
    }
    if (blueFlag) {
      goAround();
      delay(10);
      blueFlag = false;
    }

  }
}

void setup() {
  Serial.begin(9600);

  pinMode(motorAcontrolA, OUTPUT);
  pinMode(motorAcontrolB, OUTPUT);
  pinMode(motorBcontrolA, OUTPUT);
  pinMode(motorBcontrolB, OUTPUT);
  pinMode(motorAenable, OUTPUT);
  pinMode(motorBenable, OUTPUT);

  pinMode(LeftInfraRed, INPUT);
  pinMode(RightInfraRed, INPUT);

  pinMode(triggerPin, OUTPUT);
  pinMode(echoPin, INPUT);


  pinMode(frequencyDetectingPinOne, OUTPUT);
  pinMode(frequencyDetectingPinTwo, OUTPUT);
  pinMode(colourDetectingPinOne, OUTPUT);
  pinMode(colourDetectingPinTwo, OUTPUT);

  pinMode(colourSensorOutput, INPUT);

  digitalWrite(frequencyDetectingPinOne, HIGH);
  digitalWrite(frequencyDetectingPinTwo, HIGH);
  //pinMode(RightInfraRed, INPUT_PULLUP);

  analogWrite(motorAenable, 255);  //inital speed of Motors
  analogWrite(motorBenable, 255);

  pinMode(colourSensorLED, OUTPUT);
  digitalWrite(colourSensorLED, HIGH);
}
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

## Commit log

2024-06-08 Create Presentation Prototype
2024-06-19 color sensor design
2024-06-19 motor driver
2024-06-19 IR schematic
2024-06-19 ultrasonic schematic
2024-06-19 block schematic
2024-06-19 ir block schematic
